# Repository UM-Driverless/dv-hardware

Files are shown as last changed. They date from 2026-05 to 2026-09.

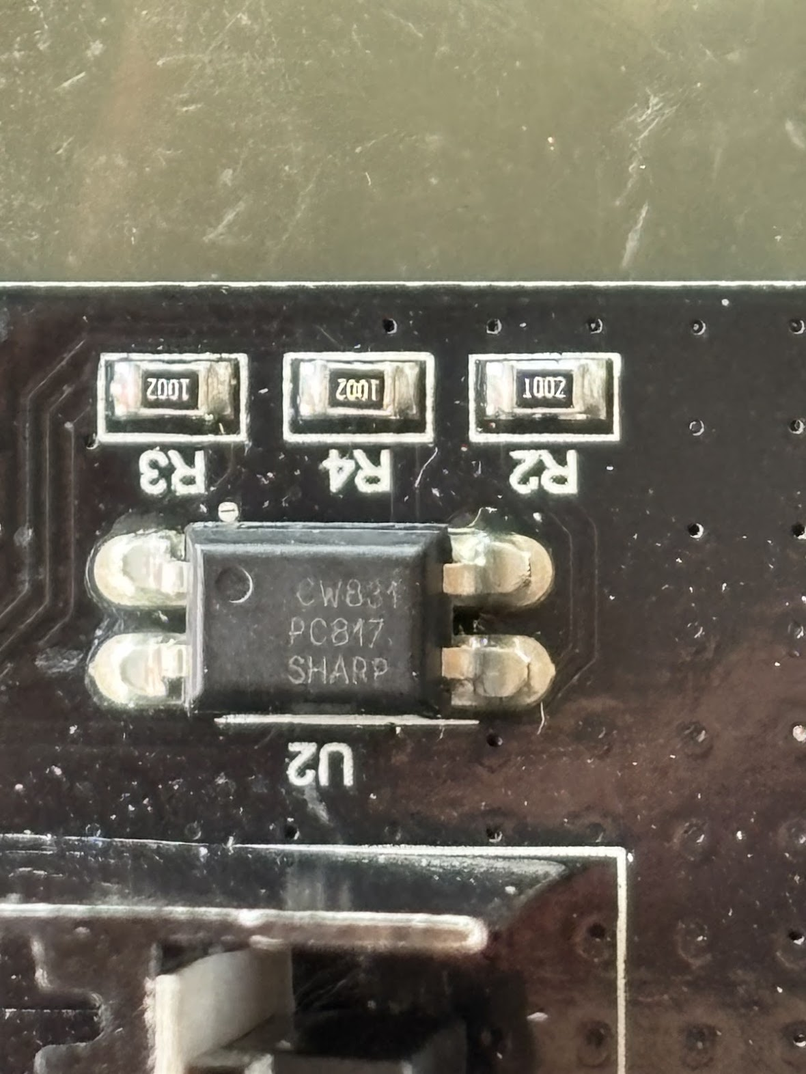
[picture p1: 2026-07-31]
projects/kart-medulla/docs/images/compressor-module-U2-PC817.png

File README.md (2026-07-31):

# dv-hardware

Hardware (KiCad) projects for the Driverless section of U-Motorsport (URJC Formula Student).

Firmware lives in [UM-Driverless/kart-medulla](https://github.com/UM-Driverless/kart-medulla). Pair board revisions with firmware releases via matching git tags (e.g. `medulla-v1.2` here, `medulla-v1.2-fw` there).

## Layout
```
lib/                 shared symbols, footprints, 3D models — referenced by every project
projects/<board>/    one folder per board (KiCad project, EasyEDA source archive,
                     the board's requirements.md, tasks.md and docs/)
tasks.md             cross-board tasks + the index of every per-board task board
fab/<board>/<rev>/   released Gerbers, BOM, pick-and-place, JLC zip
docs/                cross-board notes
.agents/             agent-readable project knowledge (history, errors)
```

## Board identity
A manufactured board is identified by the commit in this repo that its gerbers were exported from,
written on the board as a QR code or label (short hash is enough). Firmware repos quote that hash to
declare which hardware they target. Because rework exists on a physical board and in no commit, each
board also carries a rework list alongside its hash. Worked example and the boards that exist:
[`projects/kart-medulla/README.md`](projects/kart-medulla/README.md).

## Migration status
Projects originate in EasyEDA Pro and are being migrated to KiCad 9. Each `projects/<board>/` keeps:
- `easyeda-source/` — original `.epro` exports for reference (do not edit)
- `<board>.kicad_pro` (and friends) — the live KiCad project after import

## First-time setup

Install **KiCad 10.x** with the **3D shapes** package included (default in the official installer). The boards reference `${KICAD10_3DMODEL_DIR}` for standard parts (caps, resistors, SOIC, SOT, headers, …); without that variable set, the 3D viewer comes up empty.

After installing, verify the path:

- macOS: `KiCad → Settings… → Configure Paths…` → row `KICAD10_3DMODEL_DIR` should point to `/Applications/KiCad/KiCad.app/Contents/SharedSupport/3dmodels`
- Linux: `/usr/share/kicad/3dmodels`
- Windows: `C:\Program Files\KiCad\10.0\share\kicad\3dmodels`

Project-specific 3D models (parts not in KiCad's standard library — connectors, the MAX4660, …) live next to the board under `projects/<board>/3dmodels/` and are referenced via `${KIPRJMOD}/3dmodels/...` so they travel with the repo.

## Workflow
1. `git pull --rebase` before starting work.
2. One person per board at a time — coordinate in chat. KiCad files are text but not line-mergeable.
3. Commit small, commit often.
4. Run `kicad-cli sch erc` and `kicad-cli pcb drc` before fab. CI does this automatically (TODO).

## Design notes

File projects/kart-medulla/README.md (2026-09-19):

# kart-medulla

PCB pairs with the firmware in [UM-Driverless/kart-medulla](https://github.com/UM-Driverless/kart-medulla).

Originally called "ESP32 Expander" in EasyEDA (Jan 2026), renamed to "Kart Medulla (expander for ESP 32)" in May 2026. Both EasyEDA exports kept under `easyeda-source/` for diff history.

## Board identity

**A manufactured board is identified by the dv-hardware commit its gerbers were exported from**,
written on the board as a QR code or label — short form is enough, e.g. `84d6dd0`. Firmware repos
quote that hash to say which hardware they target, so "does this code match this board?" is a
question anyone can answer by reading the board.

Use the **gerber-export** commit, not the last commit that touched the schematic. They are usually
different, and only the export is what a fab house ever received.

**A board stops matching its hash the moment it is reworked.** The hash names the design it was made
from; a lifted pin or a patch wire exists on that one physical board and in no commit. So each board
also carries a rework list below. A rework entry may name the commit whose behaviour it brings the
board up to — that is how a patched board gets described precisely without inventing a new
identifier for it.

### Boards in existence

**`84d6dd0`** — "medulla: add fabrication gerbers + drill files (zip for fab)". The last commit
touching `fabrication/`, so it is the best available evidence of what the fab house received;
inferred from this repo rather than read off a purchase order. Paired with kart-brain `main` at
`c200e56`. Also reachable as the git tag `kart-medulla-v1`, which is only an alias — the hash is
what the board carries and what firmware quotes.

Two pins are also used for something other than their designed signal on this board (the steering
sensor's PWM on `PRESSURE_3`, the compressor MOSFET gate on `BUZZER`) — that is firmware assignment
rather than copper, so it is listed in
[`docs/pinout-kart-medulla-v1.md`](docs/pinout-kart-medulla-v1.md) under "As-built pin use". Read both that section
and the list below to know what this board actually does.

Rework outstanding on this board:

- **CN10.2 brake output is on the wrong side of the LM358.** The board carries the unamplified 0-5 V
  DAC output where the valve needs 0-10 V, and the U13.10 -> U1.3 copper (DAC to amplifier input) is
  unrouted. Fixed in the design by `f68cc1f`, which is *after* this board was made, so the board
  still has the fault. Needs a physical patch — see [`tasks.md`](tasks.md).
- **R10 removed, to read the steering sensor's PWM on GPIO 1.** The `PRESSURE_3` front end is
  `CN5.2 —[R8 10k]— node —[R9 10k]— GPIO 1 —[R10 10k]— GND`. R10 is the only shunt to ground, so
  removing it (and only it) turns the terminal into a usable digital input; R8 + R9 stay as a 20 kΩ
  series, which is far too high-impedance for the ADC — that is why this pin is decoded as PWM with
  the MCPWM capture peripheral rather than read as an analog voltage. Recorded here 2026-07-31; the
  reasoning and the wiring context are on the kart-docs medulla page.
- **Check for abandoned throttle-bypass rework.** The working throttle path uses MCP4922 channel A:
  a 2026-08-08 workshop video records it working with the “new DAC chip at 5 volts,” and the kart
  later accelerated on command under remote control. The record does not establish whether the
  original chip was faulty or exactly when it was changed.
  The temporary GPIO 38 filtered-PWM firmware path was reverted. Inspect this physical board for a
  leftover flying wire from GPIO 38 toward U14 pin 8 and confirm U13 pin 14 was not left lifted; remove
  the wire and restore the pin if either change was ever soldered. See the firmware repo's `tasks.md`.

## Migration status (2026-05-03)
Converted via [ConvertEDA](https://converteda.com) from EasyEDA Pro 2.2.47.7. KiCad 10.0.1's built-in `Import Non-KiCad Project → EasyEDA Pro` silently failed on this `.epro` (produced empty stubs) — likely a format-version lag against EasyEDA Pro 2.2.47.x. ConvertEDA handled it cleanly.

Renamed all internal references from `Kart_Medulla_(expander_for_ESP_32)` to `kart-medulla` (file names, sheet refs, project name, title block) for consistency with the firmware repo.

### Known cleanup needed (raw conversion baseline)
- 347 ERC violations: mostly missing `gen` symbol library (converter creates `gen:` lib_id refs but doesn't ship the library), `power` library mismatches (`12V`, `+5V_REG` not in KiCad's stdlib power), missing `fp-lib-table`.
- 165 DRC violations + 31 unconnected items: expected until footprint library is registered and net ties verified.

Cleanup work tracked separately. The current commit is the as-converted baseline so future cleanup commits show a clean diff.

## Fonts

Silkscreen text on the PCB uses **DejaVu Sans Mono**. There is no monospace font shared by default between macOS and Ubuntu, so contributors must install it locally:

- **Ubuntu:** ships by default — no action needed.
- **macOS:** `brew install --cask font-dejavu` then restart KiCad.

Alternatively, `File → Board Setup → Embedded Files` lets KiCad embed the font into the .kicad_pcb so it travels with the project. See `history.md` 2026-05-09 entry for details.

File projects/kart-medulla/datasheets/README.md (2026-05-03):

# kart-medulla datasheets

Datasheets for chips actually placed on this board. Copied in from the vault (`~/dv/datasheets/`) when a part is designed onto the PCB. Self-contained so a fresh `git clone` of `dv-hardware` gives you everything needed to understand the board.

## What goes here
- One PDF per chip used in the BOM. Filename: `<partnumber>_<vendor>_datasheet.pdf` (matches vault naming).
- Application notes specific to how *this* board uses the part.

## What does NOT go here
- Datasheets for parts only being evaluated (not yet on the PCB) → keep in vault.
- General electronics reference (op-amp theory, etc.) → vault `references/`.
- Datasheets shared across multiple boards: still copy here per-board (small duplication is OK; lookup pain isn't). The vault remains the master catalog.

## Source of truth
Vault `~/dv/datasheets/` is the team's full chip catalog. This folder is the per-board subset.

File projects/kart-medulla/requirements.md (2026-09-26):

<!-- reference — read when scoping a board revision -->

# kart-medulla — requirements

What the board must do. Durable: survives revisions and task pruning.

- **This file** = the target (what the board must do, in every revision).
- **`tasks.md`** (next to this file) = the work for this board (pruned as items are done).
  The cross-board board is the repo root `tasks.md`, which indexes it.
- **`pinout-esp32-s3.md` / `pinout-cn-connectors.md`** = the as-built pin-by-pin reality.

Signals are named here, never pin-mapped — pin assignments live in the pinout docs only.

`[built]` means the assembled board already meets it and the next revision must not lose it.
`[v2]` means the next revision has work to do. Every requirement links to its entry in
[Notes](#notes), which carries the reasoning, the numbers and the traps — read that entry
before drawing the thing. Cite requirements elsewhere by ID, not by quoting the line, so
rewording here does not break the reference.

## Requirements

- **REQ-01 — Push-in terminal connectors, rated for what they carry.** No dupont. WAGO
  2601-31xx, wires exiting outward, pin numbering co-directional with CN numbering on each
  side. `[v2]` [Why](#req-01)
- **REQ-02 — Read 3 motor hall sensors.** 5 V digital, level-translated to 3.3 V. `[built]`
  [Why](#req-02)
- **REQ-03 — Read 3 Festo pressure sensors.** 0–10 V analog. `[v2]` [Why](#req-03)
- **REQ-04 — Write the kart accelerator command.** 5 V analog. `[built]` [Why](#req-04)
- **REQ-05 — Write the Festo brake-valve command, across its full 0–10 V range.** `[v2]`
  [Why](#req-05)
- **REQ-06 — Cut the shutdown circuit on command.** `[built]` [Why](#req-06)
- **REQ-07 — Give the steering sensor its own PWM-capable input.** GPIO 38, no divider and no
  filter capacitor. `[v2]` [Why](#req-07)
- **REQ-08 — Every output that can move the kart reaches its safe state through a component,
  not through code.** Pulldowns on `CMD_STEER_PWM` and `CMD_STEER_DIR`. `[v2]` [Why](#req-08)
- **REQ-09 — Separate power and signal ground.** Distinct net classes for Power GND
  (compressor, heavy actuators) and Signal GND (ESP32, logic). `[v2]` [Why](#req-09)
- **REQ-10 — Bring at least two spare GPIOs out to terminals.** Unassigned, PWM-capable,
  non-strap. `[v2]` [Why](#req-10)
- **REQ-11 — Switch the EBS compressor on the board, motor current included.** The compressor
  MOSFET module stuck onto the assembled board today becomes part of the PCB. `[v2]`
  [Why](#req-11)
- **REQ-12 — Read the final state of the shutdown circuit.** 12 V digital input from the shutdown MOSFET. `[v2]` [Why](#req-12)
- **REQ-13 — Connect the board to a CAN bus.** 3.3 V transceiver on the board, CANH and CANL
  on terminals. `[v2]` [Why](#req-13)

**Explicitly not a requirement:** an ASSI or AS-emergency buzzer. FS-Rules DV 4.5 applies to
the formula vehicle, not this kart — Rubén, 2026-07-18. The `BUZZER` net name on GPIO 3 /
CN8.2 is historical; that pin is the compressor's permanently.

## Notes

### REQ-01 — Push-in terminal connectors, rated for what they carry

From the original brief: carry the ESP32 and make connections easier with wago-like push-in
connectors, not arduino-style dupont.

The fitted Phoenix 1990012 is rated 2 A and v2 carries the compressor's 6 A, so the connector
family changes to the team's WAGO standard (17.5 A, 3.5 mm pitch, top entry). This replaces an
earlier "rotate the push-in connectors" requirement: swapping the part makes rotating the old
one moot, and the two things that requirement wanted become placement rules for the new
footprints — **wires exit outward, away from the board, and pin numbering runs co-directional
with the CN numbering on each side.** Note the pitch change from 2.5 mm widens every connector
and affects the board outline.

### REQ-02 — Read 3 motor hall sensors

5 V digital, level-translated to 3.3 V. From the original brief; met by the assembled board.

### REQ-03 — Read 3 Festo pressure sensors

0–10 V analog, a voltage divider may suffice. **Still three. Confirmed 2026-07-31 by Rubén**,
overriding a 2026-07-18 reading that dropped it to two.

On the assembled board only two work: `PRESSURE_3` (GPIO 1, CN5.2) was repurposed to read the
steering sensor's PWM angle output. On v2 that pin goes back to `PRESSURE_3` and the steering
sensor moves to GPIO 38 — see [REQ-07](#req-07) and the v2 pin allocation in
`docs/pinout-esp32-s3.md`.

An earlier version of this said the opposite, that GPIO 1 was not coming back and the third
pressure channel needed a new pin. That is not possible: ADC1 is GPIO 1–10 and ADC2 is unusable
with WiFi on, so there are exactly ten analog-capable pins, and seven analog inputs plus the
compressor gate on GPIO 3 and I²C on GPIO 8/9 already fills them. Something non-analog has to
leave ADC1, and the steering PWM is the one that costs nothing to move.

### REQ-04 — Write the kart accelerator command

5 V analog. From the original brief; met by the assembled board.

### REQ-05 — Write the Festo brake-valve command, across its full 0–10 V range

The brake command chain is the MCP4922 DAC (0–3.3 V, since U13 moved to +3V3 on 2026-08-01) →
an LM358 ×3 non-inverting stage (U1, R19 2 kΩ / R20 1 kΩ) → the Festo VPPM proportional valve.
U1 is supplied from +12 V and the LM358 is not rail-to-rail: TI SLOS068AB §5.7 gives 3 V max
swing from the positive rail, so a worst-case part reaches only 9 V where the valve wants 10 V,
and the kart's unregulated 12 V sagging under load pushes that lower.

Accepted on the assembled board (the VPPM is ~1 bar per volt, so it costs the top ~1 bar of a
range the kart does not use) but the next revision should deliver the full range — either supply
U1 from 24 V, or fit a rail-to-rail-output op-amp in the same SOIC-8 footprint. Until it is
fixed, firmware must not treat DAC full scale as 10 bar: the achievable maximum varies between
boards, so any target above ~9 bar needs closed-loop control against a pressure sensor. Full
working and the trade-off between the two fixes: "Give the pressure-command amplifier full
0–10 V swing on the next board revision" in [`tasks.md`](tasks.md).

### REQ-06 — Cut the shutdown circuit on command

The original brief asked for a normally-open relay able to cut the shutdown circuit on
condition. The assembled board does it with a MOSFET instead of a relay (Q3, IRLZ44N, gate
pulled low by R23 so the chain sits open until firmware drives it) — the requirement is the
function, not the part.

### REQ-07 — Give the steering sensor its own PWM-capable input

Decided 2026-07-18. On the assembled board the steering sensor's PWM angle output is read on
GPIO 1, the pin silkscreened `PRES3` on CN5.2. That works, but every name still says "pressure
sensor 3", so the schematic, the netlist, the silkscreen and the firmware all describe something
the board does not do. For v2:

- **Rename the net and the silkscreen** to what it is — e.g. `STEER_SENS_PWM` — across the
  schematic, `pinout-esp32-s3.md`, `pinout-cn-connectors.md` and the firmware pin map.
- **Drop the ADC divider** on that input. It was drawn for an 0–10 V analog sensor; the steering
  sensor is a 3.3 V logic PWM output and does not want a divider in front of it.
- **Choose the pin deliberately** rather than inheriting it from a pressure channel. The sensor
  itself is not settled — AS5600, MT6701 and MA732 are all under evaluation (datasheets in the
  `kart-medulla` repo), and MT6701/MA732 offer SSI/SPI as well as PWM, so the pin choice should
  not foreclose that.
- **`STEER_SENS_PWM` moves to GPIO 38**, amended 2026-07-31 after the ADC1 count in
  [REQ-03](#req-03). GPIO 38 is unconstrained, is not a strap pin and is on neither ADC, so a PWM
  capture input wastes nothing there. `PRESSURE_3` returns to GPIO 1 with the divider it already
  has.
- **GPIO 38 must get no divider and no filter capacitor.** A 1/3 divider puts a 3.3 V logic high
  at 1.100 V against the ESP32's 2.475 V VIH, and 100 nF against that source impedance gives a
  239 Hz corner on a 994.4 Hz PWM frame. Both are correct for an analog pressure input and fatal
  for a logic-level one.

### REQ-08 — Every output that can move the kart reaches its safe state through a component

Raised 2026-08-08, after the steering swung to full lock and broke teeth off the steering gears
while the ESP32-S3 was being reflashed. The kart was in autonomous at the time and the motor was
live: the Cytron H-bridge is fed permanently from the 48 V traction pack, deliberately, so it is
powered whenever the kart is.

The board treats its actuators inconsistently, and steering is on the wrong side of the split:

- **Throttle is safe.** It passes through the MAX4660 mux (U14), whose `SELECT_THROTTLE` line
  carries a 10 kΩ pulldown (R32) to GND. An ESP32 that is unbooted, resetting, crashed or removed
  leaves the mux in manual passthrough — the driver's pedal — by physics.
- **The compressor is safe.** Its MOSFET gate has a 100 kΩ pulldown holding it off through boot.
- **Steering is not.** `CMD_STEER_PWM` and `CMD_STEER_DIR` run from the ESP32 to the Cytron with
  nothing in between and no pull resistors, so whenever the ESP32 is not actively driving them
  the motor's behaviour is whatever the floating lines happen to look like to the Cytron's
  inputs. The only thing that has ever held steering off is firmware writing zero — which does
  not exist during a reset, and a reset is part of every flash.

So: a pulldown to GND on `CMD_STEER_PWM` and on `CMD_STEER_DIR`, sized like R32 rather than
relying on the ESP32's internal pulls — the internal ones are ~45 kΩ and, more importantly, only
exist once firmware has configured them, which is exactly the window that broke the gears. Place
them at the Cytron end of each net so an unplugged connector is also covered.

Check when drawing it: the firmware drives the Cytron in sign-magnitude mode, PWM duty for
magnitude and a separate DIR pin for sign, so a low PWM line means the motor is off. **Verify the
Cytron's mode-select switches actually select that mode.** Under a locked-antiphase scheme a low
PWM line means full reverse, and the pulldown would cause the failure it is meant to prevent.

Ask the same question of every other output on the board before fab, not just this one: for each,
what does the kart do while the ESP32 is held in reset? Any answer other than "nothing" needs a
resistor.

Firmware has been changed alongside this (kart-medulla `2092130`) to drive both steering pins low
as the first action of `KM_GPIO_Init` and enable their internal pulldowns. That shortens the
undriven window to the earliest instant code can act, and does not close it — the bootloader
window remains, and only the external resistors cover it.

### REQ-09 — Separate power and signal ground

Distinct net classes for Power GND (compressor, heavy actuators) and Signal GND (ESP32, logic).

### REQ-10 — Bring at least two spare GPIOs out to terminals

Unassigned, PWM-capable, non-strap, on every revision. From 2026-07-10: *a spare pin you cannot
reach with a screwdriver is not a spare pin.* Concretely, route GPIO 38 → CN3.1 and GPIO 39 →
CN3.2; the first is the intended `CMD_COMPRESSOR_PWM`.

### REQ-11 — Switch the EBS compressor on the board, motor current included

Reconfirmed 2026-07-31: integrate it, the less wiring the better. V2 carries the MOSFET, its gate
drive, the flyback diode and the bulk capacitance, copying the already-validated module circuit
(bridge rectifier removed, 330 Ω optocoupler LED resistor for 3.3 V drive).

**Where that module is today.** On the assembled board the compressor MOSFET module is not part of
the PCB: it is a separate module stuck onto the board (Gabriel, 2026-09-26).
That is the part v2 removes. Its circuit moves into the board's own copper, so the next board is
built without a module stuck to it.

This is a power-section change before it is a component addition. The assembled board takes `+12V`
in at CN1 pin 2 and feeds only the on-board regulator for the logic/analog rail, roughly **1 mA,
7 mW**, with copper sized for that. The answer is to change the copper, not to keep the compressor
off the board: *the less wiring, the better*, and the kart currently runs two boxes that v2 is
meant to collapse into one.

**What makes it tractable is that the circuit already exists and is validated.** The compressor
MOSFET module in service has had its **bridge rectifier removed** and the **series resistor
feeding the optocoupler's LED changed to 330 Ω**, which makes its input work when driven from
3.3 V. It works, and more of the same modules are in stock. V2 copies that circuit onto the PCB
rather than designing a fresh gate-drive stage. The module has to be identified and its schematic
traced first — see the compressor task in [`tasks.md`](tasks.md).

**What v2 must get right:**

- **Track and via sizing.** `+12V` and the motor return are drawn today for a ~1 mA supply. They
  must be re-drawn (or poured) for a stated design current, with the via count to match, and that
  current written down. No component addition fixes copper sized for a different job — Rubén's
  emphasis: this is the important part.
- **A connector rated for the load**, which is what [REQ-01](#req-01) is for. The compressor
  measured **6 A running at 60 % duty** (bench, 2026-07-18). The Phoenix 1990012 terminals fitted
  as CN1–CN10 are rated **2 A** and cannot carry it. The **WAGO 2601-3103** already on the buy list
  is rated **17.5 A** and can. Deutsch **DT** (13 A per size-16 contact) is the team's harness
  standard if a sealed connector is wanted; **DTM** at 7.5 A is tight. Soldering the wire straight
  to the board is an accepted fallback. Ratings and sources:
  [`../../docs/connectors.md`](../../docs/connectors.md).
- **Nothing is gained by measuring locked-rotor inrush.** Decided 2026-07-31: the circuit is
  validated in service and over-sizing costs nothing when the parts are already in stock. Size
  generously from what is on the shelf instead of measuring the peak and designing to it.

### REQ-12 — Read the final state of the shutdown circuit

Read the final state of the shutdown circuit (the wire that goes to the MOSFET). The 12 V signal needs a voltage divider or optocoupler to step it down to a 3.3 V logic input so the ESP32 can read the emergency state.

### REQ-13 — Connect the board to a CAN bus

Decided 2026-09-26 by Gabriel, answering the question Rubén raised on 2026-07-31: is there room
for CAN on the board? The assembled board has no CAN interface; on the kart today, CAN lives on
the Orin carrier board. V2 carries one.

- **The pins cost nothing.** The pinout docs already hold two ESP32 pins for `CAN_RX` and
  `CAN_TX`. Neither is ADC-capable and neither is a strap pin, so no other signal loses its pin,
  and the GPIO expander is not involved.
- **A 3.3 V transceiver on the board**, SN65HVD230 or TCAN332 class. New part, new footprint.
  `CAN_TX` and `CAN_RX` only run from the ESP32 to the transceiver, so they never need terminals.
- **Two terminal pins for CANH and CANL.** This is the real cost: terminal positions are scarce.
  Allocate them as part of the single v2 pin and terminal allocation (see "Decide the medulla-v2
  pinout as one allocation" in [`tasks.md`](tasks.md)), not on their own.
- **Termination.** 120 Ω between CANH and CANL if the medulla is one end of the bus, nothing if it
  sits on a stub. Which one depends on where the bus runs on the kart.

**Not settled yet:** what the medulla will send or receive over CAN. The team keeps its CAN
message definitions (DBC files) in `~/dv/can/`. This requirement is the interface; the traffic is
decided with the firmware.

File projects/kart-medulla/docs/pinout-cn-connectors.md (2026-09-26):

# Push-in connector pinout (CN1–CN10)

> **Authoritative source: the schematic in this same project folder (`../kart-medulla.kicad_sch` + `../kart-medulla_P1.kicad_sch`).** This document mirrors the per-CN pin assignments for human reading. When this doc and the schematic disagree, the schematic wins; fix this file. Re-verify before each fab release.

The medulla PCB has 10 three-pin push-in (1990012) connectors arranged around the ESP32-S3 dev module. Each CN is a 3-pin Wago-style cage-clamp terminal; wires terminate independently per pin (no per-CN cable grouping is required — see `history.md` 2026-05-08 for context).

Connectors are placed in a "chip-pinout" layout to minimize jumper-wire length to the ESP32 module:

  - CN1–CN5 sit on the **right** side of the PCB, **bottom→top** (CN1 closest to USB, CN5 closest to the top edge). They map onto ESP32 pins 1–22 (right edge, RIGHT_HEADER).
  - CN6–CN10 sit on the **left** side, **top→bottom** (CN6 closest to the top edge, CN10 closest to USB). They map onto ESP32 pins 23–44 (left edge, LEFT_HEADER).

Pin numbering within each CN (verified against `kart-medulla.kicad_pcb`, 2026-07-10 — this
used to read "pin 1/2/3 from top to bottom", which is only true of the right-hand side):

  - **CN1–CN5** (right, footprint rotation −90°): pin **1 at top**, pin 3 at bottom.
  - **CN6–CN10** (left, footprint rotation +90°): pin **1 at bottom**, pin 3 at top.

Note the consequence: on the right the CNs advance bottom→top while their pins advance
top→bottom; on the left the CNs advance top→bottom while their pins advance bottom→top. So on
**both** sides the pin numbering runs *counter* to the CN numbering, and on both sides the wire
entry faces **inward**, toward the middle of the board. See the "flip the connectors" task in
`../tasks.md`.

Footprint is `CONN-TH_3P-P2.50-S5.00_1990012`: 2.50 mm pitch, and the pads are **staggered** —
pins 1 and 3 in one row, pin 2 in a row 5.00 mm across. A 180° rotation therefore moves pin 2's
pad row to the opposite side and is not a free change; the copper under each connector must be
re-routed.

## Silkscreen is the authority (v1, the only board that exists)

The table below is transcribed from the **v1 PCB silkscreen** — v1 is the only revision built, so
this is what is physically in front of you:

```
CN1        CN2        CN3        CN4       CN5        CN6        CN7        CN8         CN9          CN10
1 +3V3     1 HALL3    1 EXP_P1   1 SCL     1 HYD2     1 PED_BRK  1 PRES1    1 SDC       1 STEER_PWM  1 CMD_ACC
2 +12V     2 HALL2    2 EXP_P2   2 SDA     2 PRES3    2 PED_ACC  2 PRES2    2 BUZZ      2 HYD1       2 CMD_BRK
3 GND      3 +5V      3 EXP_P3   3 REV     3 EXP_P4   3 +3V3     3 HALL1    3 STEER_DIR 3 GND        3 GND
```

**Two naming traps, both of which have already caused confusion:**

1. **`BUZZ` on CN8.2 is an OLD name.** There is no buzzer on it. The net was repurposed to
   `CMD_COMPRESSOR_PWM` — GPIO 3 driving the EBS compressor MOSFET gate. Wherever `BUZZER` appears
   in this repo it should be read as *(old name)*. Note this collides with the rules-mandated ASSI
   buzzer, which still needs a home — see `projects/kart-medulla/tasks.md`.
2. **`EXP_P2` is CN3.2, and always has been.** A stale export of `projects/kart-medulla/output/netlist.net`
   (dated 7 May, re-exported 2026-08-10 and now current with the schematic) used to list
   `CN8.2 → /EXP_P2` and show Q3's and Q4's gates on no net at all — both artifacts of the schematic
   having moved on without a re-export. Re-exporting fixed both; the netlist now agrees with the
   silkscreen and this table. If a future edit makes them disagree again, trust the silkscreen and
   this table until the netlist is re-exported.
3. **Designator mismatch: schematic vs the fabricated v1 board.** An earlier draft of the schematic
   (before the netlist above was current) put the pressure channels on `CN2.1`/`CN2.2`/`CN2.3`. On
   the v1 silkscreen and PCB — the only board that physically exists — those pins are
   `CN7.1`/`CN7.2`/`CN5.2`, and PCB `CN2` is instead `HALL3`/`HALL2`/`+5V_REG` (see the assignment
   table below). **Anyone wiring the kart should read from the silkscreen/PCB, never from a
   schematic printout**, in case a future schematic edit drifts from the fabricated board again
   before a new revision is built.

## Assignment table

Each row is one independent terminal. `CN5.2` means connector CN5, pin 2.
The three pins in a connector do **not** imply a shared device or cable.
“Board label” is the text printed on the built board; the function describes its current use.

| Terminal | Board label | Signal and function |
|---|---|---|
| **CN1.1** | `+3V3` | `+3V3` — 3.3 V supply output from the ESP32 module. |
| **CN1.2** | `+12V` | `+12V` — 12 V supply input from the kart battery. |
| **CN1.3** | `GND` | `GND` — Ground return. |
| **CN2.1** | `HALL3` | `MOTOR_HALL_3` — Motor Hall sensor 3 input, 5 V. |
| **CN2.2** | `HALL2` | `MOTOR_HALL_2` — Motor Hall sensor 2 input, 5 V. |
| **CN2.3** | `+5V` | `+5V_REG` — 5 V rail for the motor Hall sensors. |
| **CN3.1** | `EXP_P1` | `EXP_P1` — PCF8574 expander pin P1. |
| **CN3.2** | `EXP_P2` | `EXP_P2` — PCF8574 expander pin P2. |
| **CN3.3** | `EXP_P3` | `EXP_P3` — PCF8574 expander pin P3. |
| **CN4.1** | `SCL` | `SCL` — I²C (Inter-Integrated Circuit) clock, 3.3 V. |
| **CN4.2** | `SDA` | `SDA` — I²C data, 3.3 V. |
| **CN4.3** | `REV` | `REVERSE_WIRE` — Reverse command from PCF8574 P0; open-drain output shared with the manual reverse button. |
| **CN5.1** | `HYD2` | `HYDRAULIC_2` — Hydraulic pressure sensor 2 input, 0–5 V. |
| **CN5.2** | `PRES3` | `CMD_STEER_PWM_IN` — MT6701 steering-angle input, pulse-width modulation (PWM). Repurposed pressure input; no pressure sensor here. |
| **CN5.3** | `EXP_P4` | `EXP_P4` — Spare PCF8574 expander pin P4. |
| **CN6.1** | `PED_BRK` | `PEDAL_BRAKE` — Brake pedal position input, 0–5 V. |
| **CN6.2** | `PED_ACC` | `PEDAL_ACC` — Accelerator pedal position input, 0–5 V. |
| **CN6.3** | `+3V3` | `+3V3` — 3.3 V supply output from the ESP32 module. |
| **CN7.1** | `PRES1` | `PRESSURE_1` — Pneumatic pressure sensor 1 input, 0–10 V through a divider. |
| **CN7.2** | `PRES2` | `PRESSURE_2` — Pneumatic pressure sensor 2 input, 0–10 V through a divider. |
| **CN7.3** | `HALL1` | `MOTOR_HALL_1` — Motor Hall sensor 1 input, 5 V. |
| **CN8.1** | `SDC` | `SDC_IN_LOW_SIDE` — Shutdown circuit (SDC) return, connected to Q3 drain. See voltage reference below. |
| **CN8.2** | `BUZZ` | `CMD_COMPRESSOR_PWM` — 3.3 V command to the external compressor transistor gate; not a buzzer or compressor power supply. |
| **CN8.3** | `STEER_DIR` | `CMD_STEER_DIR` — Cytron steering H-bridge direction output, 3.3 V. |
| **CN9.1** | `STEER_PWM` | `CMD_STEER_PWM` — Cytron steering H-bridge PWM output, 3.3 V. |
| **CN9.2** | `HYD1` | `HYDRAULIC_1` — Hydraulic pressure sensor 1 input, 0–5 V. |
| **CN9.3** | `GND` | `GND` — Ground return. |
| **CN10.1** | `CMD_ACC` | `CMD_ACC` — Throttle command to the motor controller, nominal 0–5 V. |
| **CN10.2** | `CMD_BRK` | `CMD_PRES` — Pressure setpoint for the Festo VPPM regulator, nominal 0–10 V. See output circuit notes below. |
| **CN10.3** | `GND` | `GND` — Ground return and reference for the VPPM setpoint; common with the 24 V supply’s 0 V. |

### Bus and sensor connections

CN4.1 and CN4.2 expose the bus shared with the on-board PCF8574 (U25). The
AS5600 connection used these bus lines; the MT6701 steering-angle PWM input is
CN5.2. CN4.3 is an independent reverse command.

CN5.2 is silkscreened `PRES3`, but its current use is steering-angle capture on
ESP32 GPIO 1. See “As-built pin use — board `84d6dd0`” in `pinout-esp32-s3.md`.
CN8.2 is silkscreened `BUZZ`, but GPIO 3 drives the gate resistor of the external
compressor MOSFET (metal-oxide-semiconductor field-effect transistor).

### Output circuit notes (CN10)

Pin 1 = throttle command, to the motor controller: MCP4922 VOUTA (0–3.3 V) goes through the LM358 U1B non-inverting stage (gain 1.51, set by R37 5.1K / R38 10K, giving 4.99 V full scale) straight to CN10.1. Nothing is muxed on this path — the MAX4660 (U14) that used to sit here has been deleted from the schematic; the panel DPDT switch on the kart, downstream of this board, is what selects whether the motor controller listens to this command or to the driver's pedal.

Pin 2 = **pressure command to the Festo VPPM proportional regulator, not to the motor controller** — braking on this kart is pneumatic. It is VOUTB amplified ×3 by the LM358 (U1A) (R19 = 2K, R20 = 1K), so 9.9 V leaves the board, not 10 V exactly, since the DAC's full scale is 3.3 V rather than 5 V — the MCP4922 U13 was moved from +5V to +3V3 on 2026-08-01 (commit 16a35fb) to fix an SPI logic-threshold problem. The net was called `CMD_BRAKE` until 2026-07-31; it is `CMD_PRES__0_10V` now, because the signal is a pressure setpoint for a proportional regulator rather than a brake-force command. The silkscreen on the built board still reads `CMD_BRK`.

Pin 3 = GND, and it is also the **return the VPPM's setpoint is measured against**: the valve runs from a separate 24 V supply, so that supply's 0 V must be common with the medulla's GND or the commanded pressure shifts by whatever the offset is.

## The pneumatic side — three devices, three supplies, only one of them on a medulla pin

Written 2026-07-31 because "the valve" was being used to mean different things. Sources:
`~/dv/kart/pneumatics/README.md` and `~/dv/kart/pneumatics/history.md` (2026-05-30).

| Device | Festo part | Its own supply | What the medulla does |
|---|---|---|---|
| **VPPM-8L proportional pressure regulator** | 571293 | **24 V DC** (21.6–26.4 V, 300 mA, 7 W) from a UENPO 9–36 V → 24 V buck-boost | Drives its **0–10 V setpoint** out of **CN10.2** (`CMD_PRES__0_10V`). GND on **CN10.3** is the return that setpoint is measured against. The medulla does **not** supply its 24 V. |
| **EBS emergency electrovalve** (and the ASB valve) | 8035174 / 8035167, VUVS-LT25 | **12 V** coils, switched by the **shutdown relay** | Nothing. No medulla pin touches it. |
| **SDE5 pressure sensors** | 567465 | 15–30 V, fed from the same 24 V rail | Reads their **0–10 V outputs** on `PRESSURE_1`/`PRESSURE_2` (CN7.1, CN7.2) through dividers |

The setpoint and the supply are different things on the VPPM: 0–10 V is the command, 24 V is what
powers the valve. When a note here says a 24 V fault could reach a medulla pin, it means the VPPM's
supply appearing on CN10.2 through a harness fault — not the EBS valve, which is 12 V and not wired
to this board at all.

The VPPM setpoint is a signal input and the LM358 drives it directly; its input impedance was
treated as an open question until 2026-07-31 and is not one.
## Voltage levels — quick reference

| Suffix in signal name | Meaning |
|---|---|
| `__3V3` | 3.3 V logic level (ESP32 native) |
| `__5V` | 5 V logic level (motor hall, level-shifted by U5 to 3V3 before reaching the ESP32) |
| `__0_5V` | analog 0–5 V (sensors, DAC outputs) |
| `__0_10V` | analog 0–10 V (pressure sensors) |
| no suffix on power names (`+12V`, `+3V3`, `+5V_REG`) | rail of that nominal voltage |

`SDC_IN_LOW_SIDE` is the drain of Q3 (IRLZ44N): nominally 0 V when Q3 conducts (no emergency), floats up to whatever the upstream SDC node sits at (≤ 12 V) when Q3 is off (emergency). Treat it as a 12-V-tolerant line.

## Power architecture summary (where each rail comes from)

  - `+12V`         — externally, from the kart battery, via **CN1 pin 2**.
  - `+5V_REG`      — on-board L7805CDT linear regulator (U19), or the external XW-1224 5 V rail tied in via the same net, feeds the `+5V_REG` global net.
  - `+3V3`         — generated by the ESP32-S3 module's on-board LDO from its 5 V input. Available on LEFT_HEADER pins 23/24 of the dev module.
  - `+5V_USB`      — independent 5 V rail from the medulla USB-C connector; powers only the ESP32 dev module (split-rail design, see `pinout-esp32-s3.md`).

The single `power:+12V` symbol that asserts the `+12V` rail name is placed at CN1 pin 2 (the entry point). Same convention applies to `+3V3` and `+5V_REG` symbols on whichever CN exports them — the symbol just declares the rail and can sit anywhere on the net.

## Cross-reference

  - ESP32 module pinout → `pinout-esp32-s3.md` (which GPIO drives which signal in the table above).
  - PCB physical layout / silkscreen → the `kart-medulla.kicad_pcb` file in this folder. The silkscreen legend that lists the 21 numbered external signals is being updated to match this assignment.
  - Decision history → `../../../history.md` entry `2026-05-08 — kart-medulla CN1–CN10 pin assignments locked to ESP32 geometry`.

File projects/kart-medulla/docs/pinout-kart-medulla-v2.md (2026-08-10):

# ESP32-S3 (WROOM-1-N16R8) — kart-medulla v2 (in progress)

> **Authoritative source: the schematic in this same project folder (`../kart-medulla.kicad_sch`).** This document mirrors the pin assignments for human reading and adds rationale/strap-pin/firmware-mode notes that the schematic doesn't carry. **PCB layout is in progress — pin assignments may shift as routing constraints surface.** When this doc and the schematic disagree, the schematic wins; fix this file. Re-verify before each fab release.
>
> **Looking for the physical kart's current wiring?** Scroll down to the **"As-built pin use — board 84d6dd0"** section. The main table below documents the v2 design currently being drawn.

Status legend (refreshed 2026-05-08):
  BLOCKED       — physically off-limits. Hardware constraint, never reclaim.
                  Examples: dev-board USB-UART bridge owns GPIO 43/44; dev-board
                  on-board RGB LED on GPIO 48; USB_D+/- pins not wired on this
                  PCB.
  HOLD          — pin works, currently unassigned, kept free for future
                  expansion. Includes octal-PSRAM-shared pins on N8R8 (GPIO
                  33-37 — usable on N8R2 but held free for module-variant
                  compatibility), conditional-strap pins (usable post-boot if
                  signal's idle-state matches the strap default), and pins
                  parked for known-but-not-yet-wired functions like CAN.
                  Don't grab without team agreement.
  NC            — pin physically not wired on this PCB rev. ERC silenced via
                  no-connect symbol.
  (signal)      — assigned, in use.

Older labels in git history: RESERVED ≈ today's BLOCKED, SPARE ≈ today's HOLD.

Each row's Notes column gives a brief reason for SPARE / RESERVED / SPARE/<sig>.

Column meanings:
  Pin        — physical-position index for the module, treated like an IC:
               bottom-right pin is **1**, count counter-clockwise around the
               ESP32-S3 dev board (component side, USB-C at the top).
                 Pins 1–22  = right edge, bottom (Pin 1) to top (Pin 22).
                 Pins 23–44 = left edge, top (Pin 23) to bottom (Pin 44).
               This is the canonical way to refer to a contact in
               conversation, on a multimeter probe, or in assembly notes.
               **Always use Pin (1–44).** Never use the schematic-symbol pin
               numbers from EasyEDA's connector parts — those are different
               (see "Schematic-symbol pin mapping" below for translation).
  Silkscreen — what's printed on the dev board next to that pin. Espressif
               labels GPIOs by their bare GPIO number (e.g. `4`, `15`, `46`)
               and adds short labels for special pins (`GND`, `3V3`, `5V`,
               `EN`, `TX`, `RX`). Useful when probing or hand-soldering.
  GPIO       — Espressif GPIO number (the one you use in firmware). Some
               pins are pure power/reset and have no GPIO.
  Signal     — net name on the schematic (see "Net Name Nomenclature" in README.md).
  Type       — peripheral / electrical role (ADC1_CHx, SPI, UART, Power, etc.).

Three references for the same physical contact:
  - "Where is it on the dev board physically?" → Pin
  - "What's printed on the board next to it?"  → Silkscreen
  - "What do I write in code?"                 → GPIO

## Schematic-symbol pin mapping

The medulla schematic uses two connector symbols:

- **RIGHT_HEADER** (on the right of the schematic, single row, 22 pins):
  the symbol's pin numbers map 1:1 to our Pin numbering. Symbol pin N = Pin N
  (for N = 1..22).
- **LEFT_HEADER** (on the left of the schematic, dual-row stacked, 44 contact
  pads but only 22 unique nets — each row is shorted between its two physical
  pads for daughterboard pass-through): symbol pins (1, 2) carry one signal,
  (3, 4) the next, etc. Each row maps to one Pin: row k → Pin (22 + k).
  - Symbol pin 1 (and 2) → Pin 23
  - Symbol pin 3 (and 4) → Pin 24
  - …
  - Symbol pin 43 (and 44) → Pin 44

(The PCB-header numbering H1.x / H2.x existed in earlier revisions of this
doc but was removed on 2026-05-02 — see `history.md`.)

Note on octal PSRAM pins (GPIO 33-37): a quad-PSRAM module (N8R2) leaves
these pins available externally. An octal-PSRAM module (N8R8 / N16R8) wires
them to the in-package PSRAM die, so they are internally reserved. The board
is laid out so it accepts either module — GPIO 35-37 are kept as SPARE on the
headers, no signal is routed to them. See history.md (2026-04-29) for rationale.

**The module actually fitted is an N16R8 (octal PSRAM)** — the supplier shipped
it instead of the ordered N8R2; verified on hardware 2026-07-10 (see
`history.md`). So on this board GPIO 33-37 are *not* reclaimable in practice:
treat them as BLOCKED, not HOLD, unless the module is swapped for a quad-PSRAM
part. The variant-agnostic layout means no signal has to move.

## Dev-board compatibility checklist (when buying a non-Espressif S3 board)

The pinout above targets the bare ESP32-S3-WROOM-1 module. Generic dev
boards (AliExpress clones, etc.) usually carry the same module on a
breakout PCB, but a few details vary between vendors and must be checked
before assuming this pinout works:

1. **Module variant.** Confirm whether the board carries an N8R2 (quad
   PSRAM, GPIO 33-37 free) or an N*R8 like N8R8 / N16R8 (octal PSRAM, GPIO
   33-37 reserved internally). The pinout is laid out to be safe with
   either — GPIO 35-37 are SPARE, GPIO 33-34 are unused, and signals that
   used to live on octal-PSRAM pins were moved (BUZZER (old name) 36→3, MOTOR_HALL_1
   37→16, CMD_STEER_DIR 35→0). So **either variant works**, but if you
   end up with an octal-PSRAM module **do not assign anything to GPIO
   33-37 in firmware**, ever.

2. **Native USB-OTG routing.** The pinout uses GPIO 19/20 as USB D-/D+ to
   the Orin. On the official Espressif DevKitC-1, two USB-C ports are
   provided: one wired to GPIO 19/20 (native USB), one to a UART bridge
   on GPIO 43/44. Generic clones vary — some wire their single USB-C only
   to a UART bridge (no native USB at all), some wire it to GPIO 19/20
   directly, some have both ports like the official board. **Verify with
   a multimeter on arrival**: continuity from the dev-board USB-C D+ pad
   to GPIO 20 and D- pad to GPIO 19. If GPIO 19/20 are not reachable
   through the on-board USB connector, the board still works for the
   medulla *only* if those GPIOs are exposed on the pin headers (so the
   medulla PCB can route them to its own USB-C connector toward the
   Orin). If 19/20 aren't broken out at all, the board is unsuitable.

3. **Physical footprint.** The medulla PCB headers (H1.1-22, H2.1-22)
   assume the Espressif **ESP32-S3-DevKitC-1** outline:
   - Board outline:           **25.40 mm × ~62.7 mm** (1000 mil × 2470 mil)
   - Pin pitch within a row:  **2.54 mm** (0.1 ″ / 100 mil)
   - Pins per row:            **22** (44 total)
   - Row-to-row centerline:   **22.86 mm** (0.9 ″ / 900 mil) —
                              pin holes sit **1.27 mm inside each PCB edge**,
                              so centerline spacing = PCB width − 2 × 1.27.
                              This is the standard Espressif DevKitC
                              footprint, kept consistent between the classic
                              ESP32-DevKitC and the S3-DevKitC-1.
   - USB-C connectors protrude ~8.00 mm past the bottom edge.

   **Confirmed by physical measurement on a teammate's official Espressif
   ESP32-S3-DevKitC-1 (2026-05-02):** caliper-imprecise centerline-to-
   centerline ≈ 24 mm, and the photo clearly shows pin centerlines inset
   from the PCB outline. 22.86 mm matches; 25.40 mm does not.

   Source documents (mirrored locally in `resources/esp32-s3-devkitc-1/`):
   - Espressif official mechanical drawing
     (`DXF_ESP32-S3-DevKitC-1_V1.1_20220429.pdf`) — board outline 25.40 mm
     and pin pitch 2.54 mm. The two `1.27 mm` callouts at the top of the
     drawing are most likely the edge-to-pin-row-centerline offsets,
     giving the 22.86 mm row spacing. The drawing is ambiguous enough
     that this was misread twice in 2026-05-01 → see `history.md` for
     the incident; trust the physical measurement and the 0.9 ″ DevKitC
     convention over any single PDF callout.
   - Espressif official schematic
     (`SCH_ESP32-S3-DevKitC-1_V1.1_20221130.pdf`) — for USB / RGB / button
     wiring; not for mechanical dimensions.

   ⚠ **Do NOT trust the UIOPAL clone vendor drawing in `resources/`** for
   this measurement. It shows `1000 mil` and `1100 mil` callouts that
   were misinterpreted as PCB-vs-outer-envelope on 2026-05-01. The
   physical measurement on the official board contradicts that reading.
   The clone may have a different layout, or the labels were misread.

   Clones (AliExpress, etc.) mostly match the official 22.86 mm footprint
   but not always — row count, board length, and row spacing have all
   been seen to differ on no-name boards. Before committing to
   manufacturing the medulla PCB, place the actual dev board on a printed
   1:1 paper copy of the footprint and confirm every pin lands on its
   pad. Photos in listings are not reliable for this.

| Pin | Silkscreen | GPIO | Signal | Type | Notes |
|---|---|---|---|---|---|
| 1 | GND | - | GND | Power | Ground (bottom of right edge / RIGHT_HEADER pin 1) |
| 2 | GND | - | GND | Power | Ground |
| 3 | 19 | 19 | NC | - | No USB-C connector on the medulla PCB. GPIO 19 is brought to the header but unwired in this rev (Orin USB link goes elsewhere). Marked NC in schematic. |
| 4 | 20 | 20 | NC | - | Same as Pin 3 — no USB connector on this board, GPIO 20 unwired. |
| 5 | 21 | 21 | MOTOR_HALL_3 | Digital In | Motor hall sensor 3 |
| 6 | 47 | 47 | MOTOR_HALL_2 | Digital In | Motor hall sensor 2 |
| 7 | 48 | 48 | BLOCKED | - | Dev-module's on-board RGB LED. No external LED on the medulla PCB. NC in schematic, BLOCKED label. |
| 8 | 45 | 45 | HOLD | - | Strap pin (VDD_SPI voltage select, flash/boot risk). Reclaimable post-boot if signal's idle state matches the strap default (LOW for 3.3V flash). |
| 9 | 0 | 0 | HOLD | - | BOOT-mode strap pin (must be HIGH at boot for normal boot). Was previously assigned to `CMD_STEER_DIR` (signal moved to GPIO 17 on 2026-05-08 to remove the strap-pin risk from real signals). Reclaimable for any signal that is HIGH or high-Z at power-on. |
| 10 | 35 | 35 | HOLD | - | Octal-PSRAM pin. Internally reserved on the fitted N16R8 — unusable in practice. Kept as HOLD (not BLOCKED) because the layout also accepts a quad-PSRAM N8R2, where it would be free. |
| 11 | 36 | 36 | HOLD | - | Octal-PSRAM pin on N8R8 — same as Pin 10. (Was briefly assigned to CMD_REVERSE on 2026-05-02; moved to PCF8574 P0 on 2026-05-03 to restore N8R8 compatibility.) |
| 12 | 37 | 37 | HOLD | - | Octal-PSRAM pin on N8R8 — same as Pin 10. |
| 13 | 38 | 38 | STEER_SENS_PWM | PWM capture (MCPWM) | MT6701 steering-angle sensor PWM output. Moved here from GPIO 1 for v2. Unconstrained, no strap, not ADC. |
| 14 | 39 | 39 | HOLD | - | Unconstrained GPIO. Earlier doc revisions described `SDC_ENABLE` here — that signal never existed in the schematic; the ESP32's contribution to the SDC chain is the GPIO driving Q3 directly (see Pin 33 / GPIO 18). |
| 15 | 40 | 40 | CMD_STEER_PWM | LEDC PWM | Steering motor PWM (Cytron H-bridge). |
| 16 | 41 | 41 | HOLD | - | Held for future CAN_RX (CAN currently moved to Orin carrier; medulla has no transceiver in this rev). |
| 17 | 42 | 42 | HOLD | - | Held for future CAN_TX (same as Pin 16). |
| 18 | 2 | 2 | HYDRAULIC_2 | ADC1_CH1 | Hydraulic pressure sensor 2 (input only) |
| 19 | 1 | 1 | PRESSURE_3 | ADC1_CH0 | Pressure sensor 3 (input only). Restored to its original analog function for v2 (steering sensor moved to GPIO 38). |
| 20 | RX | 44 | BLOCKED | - | Owned by the dev-module's USB-UART bridge (UART0 RX0). Not reclaimable — the bridge IC drives this pin from the USB-C port of the DevKitC-1. |
| 21 | TX | 43 | BLOCKED | - | Same as Pin 20 — UART0 TX0, owned by the dev-module USB-UART bridge. |
| 22 | GND | - | GND | Power | Ground (top of right edge / RIGHT_HEADER pin 22) |
| 23 | 3V3 | - | 3V3 | Power | 3.3V supply (generated by S3 module LDO from 5V input) — top of left edge / LEFT_HEADER row 1 |
| 24 | 3V3 | - | 3V3 | Power | 3.3V supply |
| 25 | EN | - | RST | Reset | Reset (Espressif silkscreens this as `EN` for chip enable) |
| 26 | 4 | 4 | PEDAL_ACC | ADC1_CH3 | Accelerator pedal (input only) |
| 27 | 5 | 5 | PEDAL_BRAKE | ADC1_CH4 | Brake pedal |
| 28 | 6 | 6 | PRESSURE_1 | ADC1_CH5 | Pressure sensor 1 (input only) |
| 29 | 7 | 7 | PRESSURE_2 | ADC1_CH6 | Pressure sensor 2 (input only) |
| 30 | 15 | 15 | SDC_STATUS | Digital In | Reads the final state of the shutdown circuit (`SDC_IN_LOW_SIDE`). The 12 V signal from the drain of Q3 passes through a 10 kΩ / 3.3 kΩ voltage divider to safely reach 3.3 V logic levels here. Assigned 2026-08-11. |
| 31 | 16 | 16 | MOTOR_HALL_1 | Digital In | Motor hall sensor 1 (moved from GPIO 37 for N8R8 compatibility) |
| 32 | 17 | 17 | CMD_STEER_DIR__3V3 | Digital Out | Steering motor direction (Cytron H-bridge). Moved here from GPIO 0 on 2026-05-08 to remove the BOOT-strap risk; now sits on the left side of the ESP32 alongside SDC_NOT_EMERGENCY. (UART1 TX default — but UART pins are remappable on ESP32-S3.) |
| 33 | 18 | 18 | SDC_NOT_EMERGENCY__3V3 | Digital Out | Drives the gate of Q3 (IRLZ44N) through R22 (100 Ω). When HIGH, Q3 conducts and pulls `SDC_IN_LOW_SIDE` to GND, completing the kart's SDC chain return path → no emergency. When LOW, Q3 is off and the SDC chain is broken → emergency. R23 (100 kΩ) gate-pulldown ensures Q3 is OFF (= emergency) at boot until firmware drives it HIGH. The signal name reads as the *intent* the ESP32 is asserting, not the chain's electrical state. Moved here from GPIO 38 on 2026-05-08 so the gate driver sits on the left side of the PCB next to the MOSFET. (UART1 RX default — remappable.) |
| 34 | 8 | 8 | SDA | I2C | I²C data — AS5600 steering angle sensor + PCF8574 I/O expander share this bus |
| 35 | 3 | 3 | CMD_COMPRESSOR_PWM | Digital Out | EBS Compressor MOSFET gate. GPIO 3 floats at reset with no internal pull, so an external pulldown wins at boot, making it safe to drive a gate. (Historically `BUZZER`, but kart carries no buzzer). |
| 36 | 46 | 46 | HOLD | - | Strap pin (ROM-print enable, flash/boot risk). Default LOW = no boot-message print, which is what we want. Reclaimable post-boot if signal's idle state is LOW at power-on. |
| 37 | 9 | 9 | SCL | I2C | I²C clock — same bus as SDA |
| 38 | 10 | 10 | HYDRAULIC_1 | ADC1_CH9 | Hydraulic pressure sensor 1 (input only) |
| 39 | 11 | 11 | MOSI | SPI | SPI data out (→ MCP4922 SDI). Also referred to as `OUT_SDI` in some parts of the schematic. |
| 40 | 12 | 12 | CLK | SPI | SPI clock (→ MCP4922 SCK). Also `OUT_SCK` in some schematic labels. |
| 41 | 13 | 13 | MISO | SPI | SPI data in. Unused by MCP4922 (write-only DAC); available for future SPI peripheral. |
| 42 | 14 | 14 | CMD_DAC_CS | SPI | MCP4922 chip select (active low). Also `OUT_CS` in some schematic labels. |
| 43 | 5V | - | +5V_USB | Power | 5V from USB VBUS via the medulla USB-C connector — powers the ESP32 dev board only (split-rail design, see history.md 2026-05-02). NOT connected to the L7805 +5V_REG rail. |
| 44 | GND | - | GND | Power | Ground (bottom of left edge / LEFT_HEADER row 22) |

## medulla-v2 pin allocation — decided 2026-07-31, as one table

Decided together rather than signal by signal, which is what let `PRESSURE_3` and `BUZZER` get
quietly repurposed on v1. Inputs to it: MT6701 stays on PWM, the MCP4922 stays as the throttle DAC,
and the op-amp keeps its 12 V rail (all Rubén, 2026-07-31).

**The constraint that drives the whole table: ADC1 is full.** On the ESP32-S3, ADC1 is GPIO 1–10 and
ADC2 is GPIO 11–20 — and ADC2 is unusable whenever WiFi is on, so in practice this board has exactly
**ten analog-capable pins**. v2 needs **seven** of them (`PEDAL_ACC`, `PEDAL_BRAKE`, `PRESSURE_1`,
`PRESSURE_2`, `PRESSURE_3`, `HYDRAULIC_1`, `HYDRAULIC_2`). All ten are currently occupied, four by
signals that are not analog at all: the steering-sensor PWM on GPIO 1, the compressor gate on GPIO 3,
and I²C on GPIO 8 and 9. Six analog + four squatters = ten, so restoring the third pressure channel
means evicting one squatter.

**Evict the steering sensor, not I²C.** Moving `STEER_SENS_PWM` from GPIO 1 to **GPIO 38** costs
nothing: GPIO 38 is an unconstrained HOLD today, is not a strap pin, is not on either ADC, and a PWM
capture input does not care which pin it sits on. That returns GPIO 1 to `PRESSURE_3`, its originally
designed use, and it is what `requirements.md` already asks for — the steering sensor gets a pin
chosen for it rather than inherited from a pressure channel. Moving I²C instead would work but
touches two pins and the firmware bus setup for no extra gain.

*(The full table that was here has been merged into the main document table above, which now serves as the authoritative v2 pinout).*

**No pin carries two signals, every strap pin is left alone, and the two ADC-capable pins spent on
non-analog signals (3 and 8/9) are spent deliberately.**

Two things this table does *not* solve, because they are connector capacity rather than GPIO
capacity: `SDC_ENABLE` still has no terminal to leave through, and CN4 gives the steering encoder its
two bus lines but neither power nor ground. See the connector audit in `tasks.md`.

**Firmware impact:** one pin number changes, `STEER_SENS_PWM` from GPIO 1 to GPIO 38. Everything else
keeps its current assignment.

## As-built pin use — board `84d6dd0`

**The table above is the *design*. This section is the *board that exists*, and it lists only the pins
whose real use differs.** Everything not listed here is used as the table says. Exceptions-only is
deliberate: a second full table would drift out of sync with the first one within a revision.

Physical modifications (cut traces, patch wires) are **not** here — they live in the per-board rework
list in [`../README.md`](../README.md), keyed to the same hash. This section is firmware-side pin
assignment; that one is copper. A person holding the board needs both.

| Pin | GPIO | Designed signal | Actual use on `84d6dd0` | Status |
|---|---|---|---|---|
| 19 | 1 | `PRESSURE_3` (ADC1_CH0) | **Reads the MT6701 steering-angle sensor's PWM output.** | Decided 2026-07-31 (Rubén). Pressure sensor 3 is not fitted on this board. |
| 35 | 3 | `BUZZER` (Digital Out) | **Drives the compressor MOSFET gate.** | Reassigned 2026-07-10 (see `../../../history.md`); and **permanent** — the kart carries no buzzer or ASSI at all (closed 2026-07-18; those are formula-vehicle only), so the `BUZZER` net name is historical. GPIO 3 floats at reset with no internal pull, so an external pulldown wins at boot — which is what makes it safe on a gate. |
| 13 | 38 | `HOLD` (unassigned) | **Planned:** raw ESP32 PWM → RC low-pass → U14 pin 8, as the throttle command, bypassing the SPI/MCP4922 path. | **Not done, and now obsolete.** It targeted the MAX4660 mux U14, which is fitted on this fabricated board but was deleted from the schematic on 2026-08-08 (a CMOS switch passes nothing unpowered, and the kart's panel DPDT switch already selects the throttle source downstream). The throttle command now leaves the board through the LM358 U1B gain stage instead. The 66 % shortfall this was meant to work around no longer exists: U1B now scales the DAC's 0–3.3 V up to 4.99 V before it leaves the board. |

Neither the pressure-3 sensor nor the buzzer is populated on this board, so both reassignments are
free — no signal was displaced. Record any further deviation here the day it is decided, not the day
the firmware is written; the point of this section is that someone probing the board can trust it.

## MCP4922 (dual 12-bit SPI DAC) — external chip connections on the PCB

| Pin | Signal | Connects to |
|---|---|---|
| VDD | +3V3 | 3.3 V rail. Moved from 5 V on 2026-08-01 (commit `16a35fb`): the MCP4922 datasheet DS22250A p7 sets VIH min = 0.7 × VDD, so a 5 V supply demanded 3.5 V on the SPI pins, which a 3.3 V ESP32 cannot reach. |
| VSS | GND | Ground |
| SHDN | +3V3 | Tied high (DAC always enabled) |
| LDAC | GND | Tied low → every SPI write latches to output immediately |
| CS | → ESP32 GPIO14 (CMD_DAC_CS) | |
| SCK | → ESP32 GPIO12 (CLK) | |
| SDI | → ESP32 GPIO11 (MOSI) | |
| VREFA | +3V3 via RC filter | 100 Ω series + 10 µF ceramic to GND, placed next to chip. Full scale on VOUTA is therefore 3.3 V. |
| VREFB | +3V3 via RC filter | 100 Ω series + 10 µF ceramic to GND (can share filter node). Full scale on VOUTB is therefore 3.3 V. |
| VOUTA | `CMD_ACC_ESP32__0_3V3` | Accelerator analog command, **0–3.3 V** at the DAC pin (U13 pin 14). It is amplified before leaving the board: U13 pin 14 → U1 pin 5 (LM358 U1B, +IN2), a non-inverting stage of gain 1.51 set by R37 5.1 kΩ and R38 10 kΩ, so full scale is **4.99 V** on U1 pin 7, which is the net `CMD_ACC__0_5V` and goes straight to CN10.1. This closes the earlier shortfall where a 3.3 V command reached only ~66 % of the motor controller's 0–5 V input range. |
| VOUTB | `CMD_PRES_DAC__0_3V3` | Pressure command, **0–3.3 V at the DAC pin**. It does not leave the board at that level: U1A (LM358) amplifies it ×3 (R19 2 kΩ / R20 1 kΩ) and CN10.2 exports **0–9.9 V** to the Festo VPPM proportional regulator. |

RC filter purpose: attenuates ~150 kHz switching ripple from the XW-1224 buck
by ~60 dB at the DAC reference pins. DAC VREF draws <100 µA so the 100 Ω
series resistor drops <10 mV (negligible vs 5V).

## Power architecture

```
Kart 12V battery ─┬─→ XW-1224 buck (external, 5A) ──→ 5V kart-wide rail
                  │                                   │
                  │                                   ├→ Medulla PCB 5V (H1.21)
                  │                                   │   │
                  │                                   │   ├→ ESP32-S3 module VIN ─→ module LDO ─→ 3.3V
                  │                                   │   └→ other on-board 3.3 V loads, including
                  │                                   │      MCP4922 VDD and its VREFA/VREFB filter
                  │                                   │
                  │                                   └→ other kart 5V loads
                  │
                  ├─→ L7805CDT linear regulator (U19, DPAK) ──→ the on-board +5V_REG rail.
                  │   THIS IS WHAT IS FITTED. Since the MAX4660 throttle mux U14 was deleted
                  │   from the schematic on 2026-08-08, this rail reaches only CN2 pin 3, plus
                  │   its own decoupling C3 (0.1 µF) and C4 (4.7 µF) — U14 was its only other
                  │   consumer. The MCP4922 (U13) moved to +3V3 on 2026-08-01 (commit 16a35fb).
                  │   The load is about 1 mA, 7 mW of heat, so a linear part is fine here. An
                  │   LM2596SX-ADJ buck (qty 8 in stock) was the alternative and was NOT taken;
                  │   settled 2026-07-31 against the schematic, where U19 = L7805CDT.
                  │
                  └─→ Cytron H-bridge 12V (steering driver) — permanently powered, NOT gated by
                      the manual/autonomous mode switch. Decision 2026-05-01: routing the Cytron
                      through the mode switch caused inrush brownouts on the Orin every time the
                      kart was switched to autonomous. See history.md (2026-05-01) for details.
                      The PCB only routes signals (CMD_STEER_PWM, CMD_STEER_DIR) to the Cytron,
                      not power. Firmware also commands PWM = 0 in manual — but that is a courtesy,
                      not the safety measure: the mode switch's second pole physically breaks the
                      cable from the Cytron to the steering motor in manual, so the motor is
                      disconnected regardless of what firmware does. Clarified 2026-08-08; the
                      earlier wording implied firmware was the only thing holding steering off.
```

## Manual/autonomous signal selection (throttle mux deleted 2026-08-08; I²C-driven reverse, decision 2026-05-01 / refined 2026-05-02 / brake-mux dropped 2026-05-08 / reverse moved to PCF8574 2026-05-03)

> **The MAX4660 throttle mux (U14) has been deleted from the schematic, on 2026-08-08.** Deleted with
> it: R32, the 10 kΩ pulldown on `SELECT_THROTTLE`, and C5, U14's local 100 nF decoupling capacitor.
> The part is still fitted on the fabricated v1 board. Two reasons for the removal:
>
> 1. **It is redundant.** The kart's panel DPDT mode switch already selects the throttle source
>    downstream of this board — the pedal or the medulla's `CMD_ACC__0_5V` on CN10.1 — so U14 was a
>    second selector in series doing the same job.
> 2. **It does not do what it was believed to do.** The design assumed U14 passed the pedal through
>    when the medulla was unpowered. It does not: it is a CMOS switch, so at V+ = 0 V both channel
>    MOSFETs are off and only ESD diodes remain, so the pedal is disconnected and instead backfeeds
>    the dead `+5V_REG` rail. "Normally closed" in the datasheet means closed at logic 0 **with power
>    applied**. The panel switch, with real metal contacts, is what actually provides the unpowered
>    manual path.
>
> The removal also resolves the open blocker that U14 ran from `+5V_REG` against a +9 V datasheet
> minimum, and it frees GPIO 15. The medulla now always outputs its autonomous throttle command and
> the panel switch decides whether anything listens. Full evidence in `history.md`, 2026-08-08.

The throttle analog signal is no longer muxed on this board: the path is MCP4922 U13 pin 14 (VOUTA,
0–3.3 V) → U1 pin 5 (LM358 U1B, +IN2), a non-inverting stage of gain 1.51 set by R37 5.1 kΩ and R38
10 kΩ giving 4.99 V full scale → U1 pin 7, the net `CMD_ACC__0_5V`, straight to CN10.1
(net `CMD_ACC__0_5V`). Brake is **not** muxed either — manual mode does not need brake control routed
through the ESP32, so the brake signal goes straight from the MCP4922 to the motor
electronics with no switch. The digital reverse signal does not use an analog switch
either — it is driven by **U25 PCF8574T port P0** (I²C GPIO expander, pin 4)
wired in parallel with the manual reverse button (wired-OR via the motor
controller's existing pull-up). The PCF8574's quasi-bidirectional outputs are
natively open-drain with a weak internal pull-up, so the wired-OR is electrically
correct without any extra components. Steering is NOT muxed (ESP32 drives the
Cytron directly; PWM = 0 in manual mode).

See `~/dv/kart/kart-medulla/history.md` for the full design history — entries
`2026-05-01` (initial PCB-mux design), `2026-05-02` (reverse refinement to
open-drain on a direct ESP32 GPIO), `2026-05-03` (reverse moved off the ESP32
onto PCF8574 P0 to free GPIO 36 and gain N8R8 compatibility), `2026-05-08`
(brake mux dropped).

| Chip / signal | Type | Manual source | Autonomous source | Output |
|---|---|---|---|---|
| **LM358 U1B, ×1.51 non-inverting (throttle)** | analog 0–3.3 V in, 0–4.99 V out | (n/a — the pedal reaches the motor electronics through the kart's panel DPDT switch, not through this board) | MCP4922 VOUTA (U13 pin 14) = `CMD_ACC_ESP32__0_3V3` | U1 pin 5 → U1 pin 7 (**R37 5.1 kΩ / R38 10 kΩ, gain 1.51**) → CN10.1 (`CMD_ACC__0_5V`). **No mux on the PCB** since U14 was deleted on 2026-08-08; the panel switch chooses between this output and the pedal. |
| **LM358 U1A, ×3 non-inverting (pressure)** | analog 0–3.3 V in, 0–9.9 V out | (n/a — manual brake bypasses ESP32) | MCP4922 VOUTB = `CMD_PRES_DAC__0_3V3` | LM358 U1A (**R19 2 kΩ / R20 1 kΩ, gain 3** as of 2026-08-01, because U13 now runs from +3V3) → `CMD_PRES__0_10V` → CN10.2 → Festo VPPM. **No mux on the PCB** — the DAC always owns the command and the only way to release it is to write zero. |
| **U25 PCF8574T pin 4 / P0** | digital | Manual reverse button (in parallel) | I²C-controlled `CMD_REVERSE` (open-drain via PCF8574) | → kart-electronics-box REVERSE wire |

No ESP32 GPIO selects the throttle source any more. GPIO 15 drove the deleted
MAX4660's SELECT pin through the net `SELECT_THROTTLE`, and is now free.

`CMD_REVERSE` is asserted by writing to PCF8574 port P0 over I²C (same bus as
`SDA__I2C` / `SCL__I2C` on ESP32 GPIO 8 / 9, shared with the AS5600 steering
sensor). The PCF8574 P0 output is in parallel with the manual reverse button.
The motor controller's REVERSE input already has its own pull-up to 5 V (that
is why the button works by pulling the line LOW). Both the button and P0 can
only sink to GND, never push HIGH actively → wired-OR with no electrical
conflict. Fail-safe property: ESP32 or I²C bus dead → P0 stays high-Z (or in
its power-on default state, all outputs high) → only the button controls the
line (identical to the current manual-only setup).

**Firmware note**: `CMD_REVERSE` is set/cleared by writing the PCF8574 output
register over I²C. The PCF8574 is quasi-bidirectional, so writing `1` releases
the line (high-Z + weak pull-up), writing `0` pulls it LOW. No special "open-drain"
mode flag needed — the chip is built that way. There is no longer a direct ESP32
GPIO-mode constraint for CMD_REVERSE.

### GPIO assignments (current schematic)

Module variant in use: **WROOM-1-N16R8** (16 MB flash, 8 MB octal PSRAM) —
verified on hardware 2026-07-10. The ESP32 GPIOs involved in manual/autonomous source selection:

| Signal | GPIO | Notes |
|---|---|---|
| `SDC_STATUS` | 15 | Reads the 12 V final state of the shutdown circuit via a 10 kΩ series / 3.3 kΩ shunt voltage divider. |
| `SDA__I2C` / `SCL__I2C` | 8 / 9 | I²C bus shared by AS5600 (steering angle) and PCF8574 (GPIO expander, drives `CMD_REVERSE` and EXP_P1..P7). |

`CMD_REVERSE` no longer consumes an ESP32 GPIO directly. With the PCF8574
indirection the design is fully N8R8-compatible — no signal depends on the
quad-PSRAM-only GPIOs (33-37).

Other signals related to this design:
- `PEDAL_ACC__0_5V` (entering at CN6.2 — CN6.1 is `PEDAL_BRAKE__0_5V`) is read by the ESP32 via ADC and nothing else on this board. It used to branch inside the schematic to the NC pin of the MAX4660 mux U14 as the manual throttle source, but U14 was deleted on 2026-08-08 and the pedal now reaches the motor electronics only through the kart's panel DPDT switch, outside this board. There is no separate `MANUAL_THR` / `PEDAL_THR` signal. Same pattern for `MANUAL_BRK`: the brake mux was dropped 2026-05-08, so manual brake never enters the medulla; the manual brake source goes directly to the brake valve driver on the kart side.
- `CMD_STEER_PWM` (GPIO 40) and `CMD_STEER_DIR` (GPIO 0) — unchanged, feed the Cytron directly with no switch in between.
- `U12` (PC357N1J000F opto with planned BSS123 swap) for driving the kart REVERSE wire is now redundant — the ESP32 GPIO open-drain output drives the line directly. **TODO**: decide whether to remove U12 from the schematic or keep it as an inline buffer. Default plan: remove for simplicity.

### Datasheet references

Datasheets live in the shared `dv/datasheets/` folder (one canonical copy per part, indexed in `dv/datasheets/README.md`). Per-board project folders hold integration-specific docs only (e.g. `kart/kart-medulla/resources/esp32-s3-devkitc-1/` keeps mechanical drawings + the local clone-vendor PDF, not the chip datasheet itself).

- **MAX4660EUA+T** (U14, the throttle mux — deleted from the schematic 2026-08-08, still fitted on the fabricated v1 board): `dv/datasheets/max4660_analogdevices_datasheet.pdf` (mirrored 2026-05-02; canonical URL <https://www.analog.com/media/en/technical-documentation/data-sheets/MAX4659-MAX4660.pdf>).
- **L7805CDT** (U19, the fitted 12 V → 5 V regulator): <https://item.szlcsc.com/datasheet/L7805CDT/21968527.html>.
- **LM2596SX-ADJ** (evaluated, not fitted): `dv/datasheets/lm2596_ti_datasheet.pdf` (mirrored 2026-05-02).

---

# Legacy: classic ESP32 (previous board, kept for reference)

| Pin | Header | GPIO | Signal | Type | Notes |
|---|---|---|---|---|---|
| 1 | H1.1 | 6 | RESERVED | - | FLASH/SDIO |
| 2 | H1.2 | 7 | RESERVED | - | FLASH/SDIO |
| 3 | H1.3 | 8 | RESERVED | - | FLASH/SDIO |
| 4 | H1.4 | 15 | RESERVED | - | STRAP pin (boot config risk) |
| 5 | H1.5 | 2 | STATUS_LED | Digital Out | Onboard LED (strap pin, keep LOW at boot) |
| 6 | H1.6 | 0 | RESERVED | - | STRAP pin (BOOT mode) |
| 7 | H1.7 | 4 | RESERVED | - | STRAP pin (boot config risk) |
| 8 | H1.8 | 16 | MOTOR_HALL_3 | Digital In | Motor hall sensor 3 (also UART2 RX) |
| 9 | H1.9 | 17 | MOTOR_HALL_1 | Digital In | Motor hall sensor 1 (also UART2 TX) |
| 10 | H1.10 | 5 | RESERVED | - | STRAP pin (boot config risk) |
| 11 | H1.11 | 18 | CMD_STEER_PWM | LEDC PWM | Steering motor PWM (Cytron H-bridge) |
| 12 | H1.12 | 19 | CMD_STEER_DIR | Digital Out | Steering motor direction (Cytron H-bridge) |
| 13 | H1.13 | - | GND | Power | Ground |
| 14 | H1.14 | 21 | I2C_SDA | I2C | AS5600 steering angle sensor data |
| 15 | H1.15 | 3 | USB_UART_RX | UART0 RX | Reserved (binary protocol from Orin) |
| 16 | H1.16 | 1 | USB_UART_TX | UART0 TX | Reserved (binary protocol to Orin) |
| 17 | H1.17 | 22 | I2C_SCL | I2C | AS5600 steering angle sensor clock |
| 18 | H1.18 | 23 | SPARE | - | Available |
| 19 | H1.19 | - | GND | Power | Ground |
| 20 | H2.1 | - | 3V3 | Power | 3.3V supply |
| 21 | H2.2 | - | EN | Reset | Active-low reset |
| 22 | H2.3 | 36 (VP) | PRESSURE_1 | ADC1_CH0 | Pressure sensor 1 (input only) |
| 23 | H2.4 | 39 (VN) | PRESSURE_2 | ADC1_CH3 | Pressure sensor 2 (input only) |
| 24 | H2.5 | 34 | PRESSURE_3 | ADC1_CH6 | Pressure sensor 3 (input only) |
| 25 | H2.6 | 35 | PEDAL_ACC | ADC1_CH7 | Accelerator pedal (input only) |
| 26 | H2.7 | 32 | PEDAL_BRAKE | ADC1_CH4 | Brake pedal |
| 27 | H2.8 | 33 | MOTOR_HALL_2 | Digital In | Motor hall sensor 2 |
| 28 | H2.9 | 25 | CMD_ACC | DAC1 | Throttle analog output (0-255) |
| 29 | H2.10 | 26 | CMD_BRAKE | DAC2 | Brake analog output (0-255) |
| 30 | H2.11 | 27 | HYDRAULIC_1 | ADC2_CH7 | Hydraulic pressure sensor 1 |
| 31 | H2.12 | 14 | HYDRAULIC_2 | ADC2_CH6 | Hydraulic pressure sensor 2 |
| 32 | H2.13 | 12 | RESERVED | - | STRAP pin (flash/boot risk) |
| 33 | H2.14 | - | GND | Power | Ground |
| 34 | H2.15 | 13 | SDC_NOT_EMERGENCY | Digital In | Shutdown circuit emergency status |
| 35 | H2.16 | 9 | RESERVED | - | FLASH/SDIO |
| 36 | H2.17 | 10 | RESERVED | - | FLASH/SDIO |
| 37 | H2.18 | 11 | RESERVED | - | FLASH/SDIO |
| 38 | H2.19 | - | 5V | Power | 5V supply |

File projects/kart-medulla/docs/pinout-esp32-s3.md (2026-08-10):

# ESP32-S3 (WROOM-1-N16R8) — current PCB

> **Authoritative source: the schematic in this same project folder (`../kart-medulla.kicad_sch`).** This document mirrors the pin assignments for human reading and adds rationale/strap-pin/firmware-mode notes that the schematic doesn't carry. **PCB layout is in progress — pin assignments may shift as routing constraints surface.** When this doc and the schematic disagree, the schematic wins; fix this file. Re-verify before each fab release.

Status legend (refreshed 2026-05-08):
  BLOCKED       — physically off-limits. Hardware constraint, never reclaim.
                  Examples: dev-board USB-UART bridge owns GPIO 43/44; dev-board
                  on-board RGB LED on GPIO 48; USB_D+/- pins not wired on this
                  PCB.
  HOLD          — pin works, currently unassigned, kept free for future
                  expansion. Includes octal-PSRAM-shared pins on N8R8 (GPIO
                  33-37 — usable on N8R2 but held free for module-variant
                  compatibility), conditional-strap pins (usable post-boot if
                  signal's idle-state matches the strap default), and pins
                  parked for known-but-not-yet-wired functions like CAN.
                  Don't grab without team agreement.
  NC            — pin physically not wired on this PCB rev. ERC silenced via
                  no-connect symbol.
  (signal)      — assigned, in use.

Older labels in git history: RESERVED ≈ today's BLOCKED, SPARE ≈ today's HOLD.

Each row's Notes column gives a brief reason for SPARE / RESERVED / SPARE/<sig>.

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

Three references for the same physical contact:
  - "Where is it on the dev board physically?" → Pin
  - "What's printed on the board next to it?"  → Silkscreen
  - "What do I write in code?"                 → GPIO

## Schematic-symbol pin mapping

The medulla schematic uses two connector symbols:

- **RIGHT_HEADER** (on the right of the schematic, single row, 22 pins):
  the symbol's pin numbers map 1:1 to our Pin numbering. Symbol pin N = Pin N
  (for N = 1..22).
- **LEFT_HEADER** (on the left of the schematic, dual-row stacked, 44 contact
  pads but only 22 unique nets — each row is shorted between its two physical
  pads for daughterboard pass-through): symbol pins (1, 2) carry one signal,
  (3, 4) the next, etc. Each row maps to one Pin: row k → Pin (22 + k).
  - Symbol pin 1 (and 2) → Pin 23
  - Symbol pin 3 (and 4) → Pin 24
  - …
  - Symbol pin 43 (and 44) → Pin 44

(The PCB-header numbering H1.x / H2.x existed in earlier revisions of this
doc but was removed on 2026-05-02 — see `history.md`.)

Note on octal PSRAM pins (GPIO 33-37): a quad-PSRAM module (N8R2) leaves
these pins available externally. An octal-PSRAM module (N8R8 / N16R8) wires
them to the in-package PSRAM die, so they are internally reserved. The board
is laid out so it accepts either module — GPIO 35-37 are kept as SPARE on the
headers, no signal is routed to them. See history.md (2026-04-29) for rationale.

**The module actually fitted is an N16R8 (octal PSRAM)** — the supplier shipped
it instead of the ordered N8R2; verified on hardware 2026-07-10 (see
`history.md`). So on this board GPIO 33-37 are *not* reclaimable in practice:
treat them as BLOCKED, not HOLD, unless the module is swapped for a quad-PSRAM
part. The variant-agnostic layout means no signal has to move.

## Dev-board compatibility checklist (when buying a non-Espressif S3 board)

The pinout above targets the bare ESP32-S3-WROOM-1 module. Generic dev
boards (AliExpress clones, etc.) usually carry the same module on a
breakout PCB, but a few details vary between vendors and must be checked
before assuming this pinout works:

1. **Module variant.** Confirm whether the board carries an N8R2 (quad
   PSRAM, GPIO 33-37 free) or an N*R8 like N8R8 / N16R8 (octal PSRAM, GPIO
   33-37 reserved internally). The pinout is laid out to be safe with
   either — GPIO 35-37 are SPARE, GPIO 33-34 are unused, and signals that
   used to live on octal-PSRAM pins were moved (BUZZER (old name) 36→3, MOTOR_HALL_1
   37→16, CMD_STEER_DIR 35→0). So **either variant works**, but if you
   end up with an octal-PSRAM module **do not assign anything to GPIO
   33-37 in firmware**, ever.

2. **Native USB-OTG routing.** The pinout uses GPIO 19/20 as USB D-/D+ to
   the Orin. On the official Espressif DevKitC-1, two USB-C ports are
   provided: one wired to GPIO 19/20 (native USB), one to a UART bridge
   on GPIO 43/44. Generic clones vary — some wire their single USB-C only
   to a UART bridge (no native USB at all), some wire it to GPIO 19/20
   directly, some have both ports like the official board. **Verify with
   a multimeter on arrival**: continuity from the dev-board USB-C D+ pad
   to GPIO 20 and D- pad to GPIO 19. If GPIO 19/20 are not reachable
   through the on-board USB connector, the board still works for the
   medulla *only* if those GPIOs are exposed on the pin headers (so the
   medulla PCB can route them to its own USB-C connector toward the
   Orin). If 19/20 aren't broken out at all, the board is unsuitable.

3. **Physical footprint.** The medulla PCB headers (H1.1-22, H2.1-22)
   assume the Espressif **ESP32-S3-DevKitC-1** outline:
   - Board outline:           **25.40 mm × ~62.7 mm** (1000 mil × 2470 mil)
   - Pin pitch within a row:  **2.54 mm** (0.1 ″ / 100 mil)
   - Pins per row:            **22** (44 total)
   - Row-to-row centerline:   **22.86 mm** (0.9 ″ / 900 mil) —
                              pin holes sit **1.27 mm inside each PCB edge**,
                              so centerline spacing = PCB width − 2 × 1.27.
                              This is the standard Espressif DevKitC
                              footprint, kept consistent between the classic
                              ESP32-DevKitC and the S3-DevKitC-1.
   - USB-C connectors protrude ~8.00 mm past the bottom edge.

   **Confirmed by physical measurement on a teammate's official Espressif
   ESP32-S3-DevKitC-1 (2026-05-02):** caliper-imprecise centerline-to-
   centerline ≈ 24 mm, and the photo clearly shows pin centerlines inset
   from the PCB outline. 22.86 mm matches; 25.40 mm does not.

   Source documents (mirrored locally in `resources/esp32-s3-devkitc-1/`):
   - Espressif official mechanical drawing
     (`DXF_ESP32-S3-DevKitC-1_V1.1_20220429.pdf`) — board outline 25.40 mm
     and pin pitch 2.54 mm. The two `1.27 mm` callouts at the top of the
     drawing are most likely the edge-to-pin-row-centerline offsets,
     giving the 22.86 mm row spacing. The drawing is ambiguous enough
     that this was misread twice in 2026-05-01 → see `history.md` for
     the incident; trust the physical measurement and the 0.9 ″ DevKitC
     convention over any single PDF callout.
   - Espressif official schematic
     (`SCH_ESP32-S3-DevKitC-1_V1.1_20221130.pdf`) — for USB / RGB / button
     wiring; not for mechanical dimensions.

   ⚠ **Do NOT trust the UIOPAL clone vendor drawing in `resources/`** for
   this measurement. It shows `1000 mil` and `1100 mil` callouts that
   were misinterpreted as PCB-vs-outer-envelope on 2026-05-01. The
   physical measurement on the official board contradicts that reading.
   The clone may have a different layout, or the labels were misread.

   Clones (AliExpress, etc.) mostly match the official 22.86 mm footprint
   but not always — row count, board length, and row spacing have all
   been seen to differ on no-name boards. Before committing to
   manufacturing the medulla PCB, place the actual dev board on a printed
   1:1 paper copy of the footprint and confirm every pin lands on its
   pad. Photos in listings are not reliable for this.

| Pin | Silkscreen | GPIO | Signal | Type | Notes |
|---|---|---|---|---|---|
| 1 | GND | - | GND | Power | Ground (bottom of right edge / RIGHT_HEADER pin 1) |
| 2 | GND | - | GND | Power | Ground |
| 3 | 19 | 19 | NC | - | No USB-C connector on the medulla PCB. GPIO 19 is brought to the header but unwired in this rev (Orin USB link goes elsewhere). Marked NC in schematic. |
| 4 | 20 | 20 | NC | - | Same as Pin 3 — no USB connector on this board, GPIO 20 unwired. |
| 5 | 21 | 21 | MOTOR_HALL_3 | Digital In | Motor hall sensor 3 |
| 6 | 47 | 47 | MOTOR_HALL_2 | Digital In | Motor hall sensor 2 |
| 7 | 48 | 48 | BLOCKED | - | Dev-module's on-board RGB LED. No external LED on the medulla PCB. NC in schematic, BLOCKED label. |
| 8 | 45 | 45 | HOLD | - | Strap pin (VDD_SPI voltage select, flash/boot risk). Reclaimable post-boot if signal's idle state matches the strap default (LOW for 3.3V flash). |
| 9 | 0 | 0 | HOLD | - | BOOT-mode strap pin (must be HIGH at boot for normal boot). Was previously assigned to `CMD_STEER_DIR` (signal moved to GPIO 17 on 2026-05-08 to remove the strap-pin risk from real signals). Reclaimable for any signal that is HIGH or high-Z at power-on. |
| 10 | 35 | 35 | HOLD | - | Octal-PSRAM pin. Internally reserved on the fitted N16R8 — unusable in practice. Kept as HOLD (not BLOCKED) because the layout also accepts a quad-PSRAM N8R2, where it would be free. |
| 11 | 36 | 36 | HOLD | - | Octal-PSRAM pin on N8R8 — same as Pin 10. (Was briefly assigned to CMD_REVERSE on 2026-05-02; moved to PCF8574 P0 on 2026-05-03 to restore N8R8 compatibility.) |
| 12 | 37 | 37 | HOLD | - | Octal-PSRAM pin on N8R8 — same as Pin 10. |
| 13 | 38 | 38 | HOLD | - | Unconstrained GPIO. Was `SDC_NOT_EMERGENCY` until 2026-05-08; signal moved to GPIO 18 (Pin 33) so Q3's gate driver could sit on the left side of the PCB next to the MOSFET. Currently free. |
| 14 | 39 | 39 | HOLD | - | Unconstrained GPIO. Earlier doc revisions described `SDC_ENABLE` here — that signal never existed in the schematic; the ESP32's contribution to the SDC chain is the GPIO driving Q3 directly (see Pin 33 / GPIO 18). |
| 15 | 40 | 40 | CMD_STEER_PWM | LEDC PWM | Steering motor PWM (Cytron H-bridge). |
| 16 | 41 | 41 | HOLD | - | Held for future CAN_RX (CAN currently moved to Orin carrier; medulla has no transceiver in this rev). |
| 17 | 42 | 42 | HOLD | - | Held for future CAN_TX (same as Pin 16). |
| 18 | 2 | 2 | HYDRAULIC_2 | ADC1_CH1 | Hydraulic pressure sensor 2 (input only) |
| 19 | 1 | 1 | CMD_STEER_PWM_IN (ex-PRESSURE_3) | PWM capture (MCPWM) | CN5.2. Retired as a pressure ADC input and repurposed to read the MT6701 steering-angle sensor's PWM output via MCPWM capture — see `km_sdir_pwm.h` and firmware's `#if`'d-out `PIN_PRESSURE_3` in `km_gpio.c`. Not an ADC channel; the old "Pressure sensor 3 (input only)" label was stale. |
| 20 | RX | 44 | BLOCKED | - | Owned by the dev-module's USB-UART bridge (UART0 RX0). Not reclaimable — the bridge IC drives this pin from the USB-C port of the DevKitC-1. |
| 21 | TX | 43 | BLOCKED | - | Same as Pin 20 — UART0 TX0, owned by the dev-module USB-UART bridge. |
| 22 | GND | - | GND | Power | Ground (top of right edge / RIGHT_HEADER pin 22) |
| 23 | 3V3 | - | 3V3 | Power | 3.3V supply (generated by S3 module LDO from 5V input) — top of left edge / LEFT_HEADER row 1 |
| 24 | 3V3 | - | 3V3 | Power | 3.3V supply |
| 25 | EN | - | RST | Reset | Reset (Espressif silkscreens this as `EN` for chip enable) |
| 26 | 4 | 4 | PEDAL_ACC | ADC1_CH3 | Accelerator pedal (input only) |
| 27 | 5 | 5 | PEDAL_BRAKE | ADC1_CH4 | Brake pedal |
| 28 | 6 | 6 | PRESSURE_1 | ADC1_CH5 | Pressure sensor 1 (input only) |
| 29 | 7 | 7 | PRESSURE_2 | ADC1_CH6 | Pressure sensor 2 (input only) |
| 30 | 15 | 15 | HOLD | - | Free and unassigned since 2026-08-08. It drove `SELECT_THROTTLE`, the SELECT pin of the U14 MAX4660 throttle mux; U14 was deleted from the schematic because a CMOS analog switch passes nothing while the board is unpowered (both channel MOSFETs are off), and because the kart's panel DPDT switch already selects the throttle source downstream on metal contacts that work unpowered. R32, the 10 kΩ pulldown on `SELECT_THROTTLE`, was deleted with it. No new function has been assigned to this pin. |
| 31 | 16 | 16 | MOTOR_HALL_1 | Digital In | Motor hall sensor 1 (moved from GPIO 37 for N8R8 compatibility) |
| 32 | 17 | 17 | CMD_STEER_DIR__3V3 | Digital Out | Steering motor direction (Cytron H-bridge). Moved here from GPIO 0 on 2026-05-08 to remove the BOOT-strap risk; now sits on the left side of the ESP32 alongside SDC_NOT_EMERGENCY. (UART1 TX default — but UART pins are remappable on ESP32-S3.) |
| 33 | 18 | 18 | SDC_NOT_EMERGENCY__3V3 | Digital Out | Drives the gate of Q3 (IRLZ44N) through R22 (100 Ω). When HIGH, Q3 conducts and pulls `SDC_IN_LOW_SIDE` to GND, completing the kart's SDC chain return path → no emergency. When LOW, Q3 is off and the SDC chain is broken → emergency. R23 (100 kΩ) gate-pulldown ensures Q3 is OFF (= emergency) at boot until firmware drives it HIGH. The signal name reads as the *intent* the ESP32 is asserting, not the chain's electrical state. Moved here from GPIO 38 on 2026-05-08 so the gate driver sits on the left side of the PCB next to the MOSFET. (UART1 RX default — remappable.) |
| 34 | 8 | 8 | SDA | I2C | I²C data — AS5600 steering angle sensor + PCF8574 I/O expander share this bus |
| 35 | 3 | 3 | BUZZER (old name) | Digital Out | Buzzer for debugging. Moved from GPIO 36 for octal-PSRAM compatibility. **Correction 2026-07-10:** this row used to claim "strap pin: JTAG src select, default high". Both halves are wrong on our hardware. (a) `STRAP_JTAG_SEL` eFuse is **not burned** (read from the chip), so GPIO 3 is never sampled as a strap. (b) GPIO 3 has **no internal pull at reset** — measured `IO_MUX_GPIO3 = 0x0a02` (neither FUN_WPU bit 8 nor FUN_WPD bit 7), against controls GPIO 0 = `0x0b02` (pull-up) and GPIO 45/46 = `0x0a82` (pull-down). It floats, so an external pulldown wins at boot. That makes GPIO 3 safe to drive a MOSFET gate — see the compressor reassignment in `history.md` 2026-07-10. |
| 36 | 46 | 46 | HOLD | - | Strap pin (ROM-print enable, flash/boot risk). Default LOW = no boot-message print, which is what we want. Reclaimable post-boot if signal's idle state is LOW at power-on. |
| 37 | 9 | 9 | SCL | I2C | I²C clock — same bus as SDA |
| 38 | 10 | 10 | HYDRAULIC_1 | ADC1_CH9 | Hydraulic pressure sensor 1 (input only) |
| 39 | 11 | 11 | MOSI | SPI | SPI data out (→ MCP4922 SDI). Also referred to as `OUT_SDI` in some parts of the schematic. |
| 40 | 12 | 12 | CLK | SPI | SPI clock (→ MCP4922 SCK). Also `OUT_SCK` in some schematic labels. |
| 41 | 13 | 13 | MISO | SPI | SPI data in. Unused by MCP4922 (write-only DAC); available for future SPI peripheral. |
| 42 | 14 | 14 | CMD_DAC_CS | SPI | MCP4922 chip select (active low). Also `OUT_CS` in some schematic labels. |
| 43 | 5V | - | +5V_USB | Power | 5V from USB VBUS via the medulla USB-C connector — powers the ESP32 dev board only (split-rail design, see history.md 2026-05-02). NOT connected to the L7805 +5V_REG rail. |
| 44 | GND | - | GND | Power | Ground (bottom of left edge / LEFT_HEADER row 22) |

## medulla-v2 pin allocation — decided 2026-07-31, as one table

Decided together rather than signal by signal, which is what let `PRESSURE_3` and `BUZZER` get
quietly repurposed on v1. Inputs to it: MT6701 stays on PWM, the MCP4922 stays as the throttle DAC,
and the op-amp keeps its 12 V rail (all Rubén, 2026-07-31).

**The constraint that drives the whole table: ADC1 is full.** On the ESP32-S3, ADC1 is GPIO 1–10 and
ADC2 is GPIO 11–20 — and ADC2 is unusable whenever WiFi is on, so in practice this board has exactly
**ten analog-capable pins**. v2 needs **seven** of them (`PEDAL_ACC`, `PEDAL_BRAKE`, `PRESSURE_1`,
`PRESSURE_2`, `PRESSURE_3`, `HYDRAULIC_1`, `HYDRAULIC_2`). All ten are currently occupied, four by
signals that are not analog at all: the steering-sensor PWM on GPIO 1, the compressor gate on GPIO 3,
and I²C on GPIO 8 and 9. Six analog + four squatters = ten, so restoring the third pressure channel
means evicting one squatter.

**Evict the steering sensor, not I²C.** Moving `STEER_SENS_PWM` from GPIO 1 to **GPIO 38** costs
nothing: GPIO 38 is an unconstrained HOLD today, is not a strap pin, is not on either ADC, and a PWM
capture input does not care which pin it sits on. That returns GPIO 1 to `PRESSURE_3`, its originally
designed use, and it is what `requirements.md` already asks for — the steering sensor gets a pin
chosen for it rather than inherited from a pressure channel. Moving I²C instead would work but
touches two pins and the firmware bus setup for no extra gain.

| GPIO | v2 signal | Why this pin |
|---|---|---|
| 1 | `PRESSURE_3` | ADC1_CH0. Returns to its designed use. |
| 2 | `HYDRAULIC_2` | ADC1_CH1, unchanged |
| 3 | `CMD_COMPRESSOR_PWM` | Unchanged, and deliberately: GPIO 3 floats at reset with no internal pull, so an external pulldown wins at boot. That is what makes it safe on a MOSFET gate. |
| 4 | `PEDAL_ACC` | ADC1_CH3, unchanged |
| 5 | `PEDAL_BRAKE` | ADC1_CH4, unchanged |
| 6 | `PRESSURE_1` | ADC1_CH5, unchanged |
| 7 | `PRESSURE_2` | ADC1_CH6, unchanged |
| 8 | `SDA` | I²C, unchanged. Costs an ADC1 pin but moving it buys nothing once the steering sensor has left. |
| 9 | `SCL` | I²C, unchanged |
| 10 | `HYDRAULIC_1` | ADC1_CH9, unchanged |
| 11 | `MOSI` | SPI to MCP4922, unchanged |
| 12 | `CLK` | SPI, unchanged |
| 13 | `MISO` | Unused — MCP4922 is write-only. Free pin, left as a spare. |
| 14 | `CMD_DAC_CS` | SPI chip select, unchanged |
| 15 | *free, unassigned* | Held `SELECT_THROTTLE` for the MAX4660 throttle mux until that mux (U14) was deleted from the schematic on 2026-08-08, together with its 10 kΩ pulldown R32. No replacement function is assigned. |
| 16 | `MOTOR_HALL_1` | unchanged |
| 17 | `CMD_STEER_DIR` | unchanged |
| 18 | `SDC_NOT_EMERGENCY` | Drives Q3's gate. Stays on a real pin — a safety read must not sit behind a bus transaction. |
| 21 | `MOTOR_HALL_3` | unchanged |
| 38 | **`STEER_SENS_PWM`** | **New.** MT6701 PWM angle capture, moved off GPIO 1. Unconstrained, no strap, not ADC. |
| 39 | *spare, reachable* | The remaining unconstrained GPIO, and genuinely unclaimed. `SDC_ENABLE` held a claim on it in earlier revisions; dropped 2026-08-01 — the shutdown loop is closed by Q3 off GPIO 18, and `SDC_ENABLE` was never a net. |
| 40 | `CMD_STEER_PWM` | unchanged |
| 41 | `CAN_RX` | Already reserved for CAN. Not ADC, not a strap pin. |
| 42 | `CAN_TX` | Already reserved for CAN. |
| 47 | `MOTOR_HALL_2` | unchanged |
| 0, 45, 46 | strap pins — leave HOLD | boot behaviour risk |
| 35, 36, 37 | unusable | octal PSRAM on the fitted N16R8 |
| 48 | BLOCKED | module's own RGB LED |
| 19, 20 | NC | USB pins, no connector on this board |

**No pin carries two signals, every strap pin is left alone, and the two ADC-capable pins spent on
non-analog signals (3 and 8/9) are spent deliberately.**

Two things this table does *not* solve, because they are connector capacity rather than GPIO
capacity: `SDC_ENABLE` still has no terminal to leave through, and CN4 gives the steering encoder its
two bus lines but neither power nor ground. See the connector audit in `tasks.md`.

**Firmware impact:** one pin number changes, `STEER_SENS_PWM` from GPIO 1 to GPIO 38. Everything else
keeps its current assignment.

## As-built pin use — board `84d6dd0`

**The table above is the *design*. This section is the *board that exists*, and it lists only the pins
whose real use differs.** Everything not listed here is used as the table says. Exceptions-only is
deliberate: a second full table would drift out of sync with the first one within a revision.

Physical modifications (cut traces, patch wires) are **not** here — they live in the per-board rework
list in [`../README.md`](../README.md), keyed to the same hash. This section is firmware-side pin
assignment; that one is copper. A person holding the board needs both.

| Pin | GPIO | Designed signal | Actual use on `84d6dd0` | Status |
|---|---|---|---|---|
| 19 | 1 | `PRESSURE_3` (ADC1_CH0) | **Reads the MT6701 steering-angle sensor's PWM output.** | Decided 2026-07-31 (Rubén). Pressure sensor 3 is not fitted on this board. |
| 35 | 3 | `BUZZER` (Digital Out) | **Drives the compressor MOSFET gate.** | Reassigned 2026-07-10 (see `../../../history.md`); and **permanent** — the kart carries no buzzer or ASSI at all (closed 2026-07-18; those are formula-vehicle only), so the `BUZZER` net name is historical. GPIO 3 floats at reset with no internal pull, so an external pulldown wins at boot — which is what makes it safe on a gate. |
| 13 | 38 | `HOLD` (unassigned) | **Planned:** raw ESP32 PWM → RC low-pass → U14 pin 8, as the throttle command, bypassing the SPI/MCP4922 path. | **Not done, and now obsolete.** It targeted the MAX4660 mux U14, which is fitted on this fabricated board but was deleted from the schematic on 2026-08-08 (a CMOS switch passes nothing unpowered, and the kart's panel DPDT switch already selects the throttle source downstream). The throttle command now leaves the board through the LM358 U1B gain stage instead. The 66 % shortfall this was meant to work around no longer exists: U1B now scales the DAC's 0–3.3 V up to 4.99 V before it leaves the board. |

Neither the pressure-3 sensor nor the buzzer is populated on this board, so both reassignments are
free — no signal was displaced. Record any further deviation here the day it is decided, not the day
the firmware is written; the point of this section is that someone probing the board can trust it.

## MCP4922 (dual 12-bit SPI DAC) — external chip connections on the PCB

| Pin | Signal | Connects to |
|---|---|---|
| VDD | +3V3 | 3.3 V rail. Moved from 5 V on 2026-08-01 (commit `16a35fb`): the MCP4922 datasheet DS22250A p7 sets VIH min = 0.7 × VDD, so a 5 V supply demanded 3.5 V on the SPI pins, which a 3.3 V ESP32 cannot reach. |
| VSS | GND | Ground |
| SHDN | +3V3 | Tied high (DAC always enabled) |
| LDAC | GND | Tied low → every SPI write latches to output immediately |
| CS | → ESP32 GPIO14 (CMD_DAC_CS) | |
| SCK | → ESP32 GPIO12 (CLK) | |
| SDI | → ESP32 GPIO11 (MOSI) | |
| VREFA | +3V3 via RC filter | 100 Ω series + 10 µF ceramic to GND, placed next to chip. Full scale on VOUTA is therefore 3.3 V. |
| VREFB | +3V3 via RC filter | 100 Ω series + 10 µF ceramic to GND (can share filter node). Full scale on VOUTB is therefore 3.3 V. |
| VOUTA | `CMD_ACC_ESP32__0_3V3` | Accelerator analog command, **0–3.3 V** at the DAC pin (U13 pin 14). It is amplified before leaving the board: U13 pin 14 → U1 pin 5 (LM358 U1B, +IN2), a non-inverting stage of gain 1.51 set by R37 5.1 kΩ and R38 10 kΩ, so full scale is **4.99 V** on U1 pin 7, which is the net `CMD_ACC__0_5V` and goes straight to CN10.1. This closes the earlier shortfall where a 3.3 V command reached only ~66 % of the motor controller's 0–5 V input range. |
| VOUTB | `CMD_PRES_DAC__0_3V3` | Pressure command, **0–3.3 V at the DAC pin**. It does not leave the board at that level: U1A (LM358) amplifies it ×3 (R19 2 kΩ / R20 1 kΩ) and CN10.2 exports **0–9.9 V** to the Festo VPPM proportional regulator. |

RC filter purpose: attenuates ~150 kHz switching ripple from the XW-1224 buck
by ~60 dB at the DAC reference pins. DAC VREF draws <100 µA so the 100 Ω
series resistor drops <10 mV (negligible vs 5V).

## Power architecture

```
Kart 12V battery ─┬─→ XW-1224 buck (external, 5A) ──→ 5V kart-wide rail
                  │                                   │
                  │                                   ├→ Medulla PCB 5V (H1.21)
                  │                                   │   │
                  │                                   │   ├→ ESP32-S3 module VIN ─→ module LDO ─→ 3.3V
                  │                                   │   └→ other on-board 3.3 V loads, including
                  │                                   │      MCP4922 VDD and its VREFA/VREFB filter
                  │                                   │
                  │                                   └→ other kart 5V loads
                  │
                  ├─→ L7805CDT linear regulator (U19, DPAK) ──→ the on-board +5V_REG rail.
                  │   THIS IS WHAT IS FITTED. Since the MAX4660 throttle mux U14 was deleted
                  │   from the schematic on 2026-08-08, this rail reaches only CN2 pin 3, plus
                  │   its own decoupling C3 (0.1 µF) and C4 (4.7 µF) — U14 was its only other
                  │   consumer. The MCP4922 (U13) moved to +3V3 on 2026-08-01 (commit 16a35fb).
                  │   The load is about 1 mA, 7 mW of heat, so a linear part is fine here. An
                  │   LM2596SX-ADJ buck (qty 8 in stock) was the alternative and was NOT taken;
                  │   settled 2026-07-31 against the schematic, where U19 = L7805CDT.
                  │
                  └─→ Cytron H-bridge 12V (steering driver) — permanently powered, NOT gated by
                      the manual/autonomous mode switch. Decision 2026-05-01: routing the Cytron
                      through the mode switch caused inrush brownouts on the Orin every time the
                      kart was switched to autonomous. See history.md (2026-05-01) for details.
                      The PCB only routes signals (CMD_STEER_PWM, CMD_STEER_DIR) to the Cytron,
                      not power. Firmware also commands PWM = 0 in manual — but that is a courtesy,
                      not the safety measure: the mode switch's second pole physically breaks the
                      cable from the Cytron to the steering motor in manual, so the motor is
                      disconnected regardless of what firmware does. Clarified 2026-08-08; the
                      earlier wording implied firmware was the only thing holding steering off.
```

## Manual/autonomous signal selection (throttle mux deleted 2026-08-08; I²C-driven reverse, decision 2026-05-01 / refined 2026-05-02 / brake-mux dropped 2026-05-08 / reverse moved to PCF8574 2026-05-03)

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

The throttle analog signal is no longer muxed on this board: the path is MCP4922 U13 pin 14 (VOUTA,
0–3.3 V) → U1 pin 5 (LM358 U1B, +IN2), a non-inverting stage of gain 1.51 set by R37 5.1 kΩ and R38
10 kΩ giving 4.99 V full scale → U1 pin 7, the net `CMD_ACC__0_5V`, straight to CN10.1
(net `CMD_ACC__0_5V`). Brake is **not** muxed either — manual mode does not need brake control routed
through the ESP32, so the brake signal goes straight from the MCP4922 to the motor
electronics with no switch. The digital reverse signal does not use an analog switch
either — it is driven by **U25 PCF8574T port P0** (I²C GPIO expander, pin 4)
wired in parallel with the manual reverse button (wired-OR via the motor
controller's existing pull-up). The PCF8574's quasi-bidirectional outputs are
natively open-drain with a weak internal pull-up, so the wired-OR is electrically
correct without any extra components. Steering is NOT muxed (ESP32 drives the
Cytron directly; PWM = 0 in manual mode).

See `~/dv/kart/kart-medulla/history.md` for the full design history — entries
`2026-05-01` (initial PCB-mux design), `2026-05-02` (reverse refinement to
open-drain on a direct ESP32 GPIO), `2026-05-03` (reverse moved off the ESP32
onto PCF8574 P0 to free GPIO 36 and gain N8R8 compatibility), `2026-05-08`
(brake mux dropped).

| Chip / signal | Type | Manual source | Autonomous source | Output |
|---|---|---|---|---|
| **LM358 U1B, ×1.51 non-inverting (throttle)** | analog 0–3.3 V in, 0–4.99 V out | (n/a — the pedal reaches the motor electronics through the kart's panel DPDT switch, not through this board) | MCP4922 VOUTA (U13 pin 14) = `CMD_ACC_ESP32__0_3V3` | U1 pin 5 → U1 pin 7 (**R37 5.1 kΩ / R38 10 kΩ, gain 1.51**) → CN10.1 (`CMD_ACC__0_5V`). **No mux on the PCB** since U14 was deleted on 2026-08-08; the panel switch chooses between this output and the pedal. |
| **LM358 U1A, ×3 non-inverting (pressure)** | analog 0–3.3 V in, 0–9.9 V out | (n/a — manual brake bypasses ESP32) | MCP4922 VOUTB = `CMD_PRES_DAC__0_3V3` | LM358 U1A (**R19 2 kΩ / R20 1 kΩ, gain 3** as of 2026-08-01, because U13 now runs from +3V3) → `CMD_PRES__0_10V` → CN10.2 → Festo VPPM. **No mux on the PCB** — the DAC always owns the command and the only way to release it is to write zero. |
| **U25 PCF8574T pin 4 / P0** | digital | Manual reverse button (in parallel) | I²C-controlled `CMD_REVERSE` (open-drain via PCF8574) | → kart-electronics-box REVERSE wire |

No ESP32 GPIO selects the throttle source any more. GPIO 15 drove the deleted
MAX4660's SELECT pin through the net `SELECT_THROTTLE`, and is now free.

`CMD_REVERSE` is asserted by writing to PCF8574 port P0 over I²C (same bus as
`SDA__I2C` / `SCL__I2C` on ESP32 GPIO 8 / 9, shared with the AS5600 steering
sensor). The PCF8574 P0 output is in parallel with the manual reverse button.
The motor controller's REVERSE input already has its own pull-up to 5 V (that
is why the button works by pulling the line LOW). Both the button and P0 can
only sink to GND, never push HIGH actively → wired-OR with no electrical
conflict. Fail-safe property: ESP32 or I²C bus dead → P0 stays high-Z (or in
its power-on default state, all outputs high) → only the button controls the
line (identical to the current manual-only setup).

**Firmware note**: `CMD_REVERSE` is set/cleared by writing the PCF8574 output
register over I²C. The PCF8574 is quasi-bidirectional, so writing `1` releases
the line (high-Z + weak pull-up), writing `0` pulls it LOW. No special "open-drain"
mode flag needed — the chip is built that way. There is no longer a direct ESP32
GPIO-mode constraint for CMD_REVERSE.

### GPIO assignments (current schematic)

Module variant in use: **WROOM-1-N16R8** (16 MB flash, 8 MB octal PSRAM) —
verified on hardware 2026-07-10. The ESP32 GPIOs involved in manual/autonomous source selection:

| Signal | GPIO | Notes |
|---|---|---|
| *none* | 15 | Free and unassigned. It drove `SELECT_THROTTLE` into the MAX4660 (U14) SELECT pin until U14 and its 10 kΩ pulldown R32 were deleted from the schematic on 2026-08-08. |
| `SDA__I2C` / `SCL__I2C` | 8 / 9 | I²C bus shared by AS5600 (steering angle) and PCF8574 (GPIO expander, drives `CMD_REVERSE` and EXP_P1..P7). |

`CMD_REVERSE` no longer consumes an ESP32 GPIO directly. With the PCF8574
indirection the design is fully N8R8-compatible — no signal depends on the
quad-PSRAM-only GPIOs (33-37).

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

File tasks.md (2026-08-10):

<!-- read in full — kept under 150 lines -->

# Tasks

The repo's cross-board task board, and the index of every other task board in the repo. Update status as you go: `TODO → In Progress → Done`. Read before editing; claim by adding `[YYYY-MM-DD <name>]` and the section change.

## Task boards
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

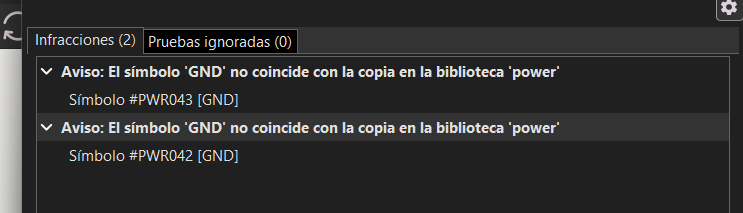
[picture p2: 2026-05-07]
.agents/image.png

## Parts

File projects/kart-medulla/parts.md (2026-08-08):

<!-- consult selectively — grep, never read in full -->

# Parts sourcing

Per-part provenance for symbols, footprints, 3D models, and datasheets used on this board. Add an entry whenever a new part is integrated. Datasheets themselves live in `datasheets/` per the convention in `datasheets/README.md`; this file just tracks where each artifact came from.

## MAX4660EUA+T (U14 — throttle SPDT mux) — NO LONGER IN THE DESIGN

**Removed from the schematic on 2026-08-08**, together with R32 (the 10 kΩ pulldown on
`SELECT_THROTTLE`) and C5 (U14's local 100 nF decoupling capacitor). Two reasons: it is a CMOS analog
switch, so with the board unpowered both channel MOSFETs are off and the driver's pedal was **not**
passed through — "normally closed" in the datasheet means closed at logic 0 with power applied, not
closed without power; and the kart's panel DPDT switch, downstream of this board, already selects the
throttle source on metal contacts that work with everything unpowered. The throttle command now runs
MCP4922 U13 pin 14 → LM358 U1B (gain 1.51) → CN10.1, with no analog switch in the path, and
GPIO 15 is free.

The part **is fitted on the fabricated v1 board**, so the sourcing details below are kept for anyone
working on that hardware.

- **Manufacturer:** Maxim Integrated (now part of Analog Devices)
- **Package:** 8-µMAX-EP (8-uSOP-EP)
- **Datasheet:** [`datasheets/MAX4660-MAX4662_Maxim_datasheet.pdf`](datasheets/MAX4660-MAX4662_Maxim_datasheet.pdf) — also at https://www.analog.com/MAX4660/datasheet
- **Symbol source:** project library (`kart-medulla.kicad_sym`, entry `MAX4660EUA_T`). Originally from EasyEDA-Pro export, ConvertEDA-migrated 2026-05-03. Pin numbering verified against SnapEDA-verified symbol on 2026-05-07. Not replaced — pin layout matches SnapEDA exactly, replacing would have broken existing wire positions.
- **Footprint source:** SnapEDA. Downloaded 2026-05-07 from https://www.snapeda.com/parts/MAX4660EUA%2BT/Maxim+Integrated/view-part/. File: `kart-medulla.pretty/SOP65P490X110-9N.kicad_mod`. Replaced the original ConvertEDA-migrated `UMAX-8_L3.0-W3.0-P0.65-LS4.9-BL-EP.kicad_mod` (still in the .pretty/ folder, unused).
- **3D model source:** SnapEDA (same download). File: `3dmodels/MAX4660EUA_T.step`.
- **Notes:** symbol has two pins both named "NC" — pin 2 is "Normally Closed" switch terminal (Passive), pin 5 is "No Connect" / do-not-wire (no_connect). See history.md 2026-05-07 entries for the full audit trail.
## LM358DR (U1 — pressure-command amplifier 0–3.3 V → 0–9.9 V, and throttle buffer)

- **Manufacturer:** Texas Instruments. Dual op-amp, SOIC-8. U1A is the non-inverting pressure-command stage, gain 3 set by R19 2 kΩ feedback and R20 1 kΩ to GND, taking MCP4922 U13 pin 10 (VOUTB, 0–3.3 V) and giving 9.9 V out. It was gain 2 with R19 = 1 kΩ until 2026-08-01 (commit `16a35fb`), when U13 moved from +5V to +3V3 and the lower full scale had to be made up in the gain; U1B is the non-inverting throttle stage, gain 1.51 set by R37 5.1 kΩ and R38 10 kΩ, taking MCP4922 U13 pin 14 (VOUTA, 0–3.3 V) in at U1 pin 5 and giving 4.99 V full scale at U1 pin 7, which is the net `CMD_ACC__0_5V` and reaches CN10.1 directly. A 1 kΩ series resistor R39 sat between the two until 2026-08-08; it existed only to limit current into the MAX4660's ESD diodes, so it was deleted when that part was.
- **Datasheet:** [`datasheets/LM358_TI_datasheet.pdf`](datasheets/LM358_TI_datasheet.pdf) — SLOS068AB, June 1976 rev. October 2024, covering LM158/158A/258/258A/358/358A/358B/358BA/2904/2904B/2904BA/2904V. Downloaded 2026-07-30 from https://www.ti.com/lit/ds/symlink/lm358.pdf. Also copied to the vault catalog at `~/dv/datasheets/LM358_TI_datasheet.pdf`.
- **The section that matters:** §5.7 "Electrical Characteristics: LM358, LM358A" — the plain LM358 grade, which is what `LM358DR` is. The B/BA grades in the same document have *different* specs (notably a 3 V–36 V supply range and much smaller output headroom), so reading the wrong table gives an over-optimistic answer.
- **Output swing from the positive rail** (§5.7, "OUTPUT" block): 2 V typ / **3 V max** at RL ≥ 10 kΩ; 4 V max at RL = 2 kΩ over 0–70 °C. The part is not rail-to-rail. On the board's +12 V rail this caps the guaranteed output at 9 V, below the 10 V the stage is asked to deliver. **Accepted, not a defect to fix on this board** — decided 2026-07-30, because the Festo VPPM regulates ~1 bar per volt and 9 bar of brake pressure is enough. Tracked for the next revision as "Give the pressure-command amplifier full 0–10 V swing on the next board revision" in `dv-hardware/projects/kart-medulla/tasks.md`; numbers and the firmware consequence are in the 2026-07-30 entry of `dv-hardware/history.md`.
- **Symbol source:** project library (`kart-medulla.kicad_sym`), split into a proper multi-unit symbol on 2026-05-04 during the ERC cleanup (it arrived from the EasyEDA-Pro export as a single flat symbol).

## MCP4922-E/SL — dual 12-bit SPI DAC (U13)

- **Manufacturer:** Microchip. Dual 12-bit voltage-output DAC, SOIC-14. Channel A is the throttle
  command (`CMD_ACC_ESP32__0_3V3`, into the LM358 U1B ×1.51 stage that drives CN10.1 — it fed the
  MAX4660 mux U14 until U14 was deleted from the schematic on 2026-08-08); channel B is the pressure command
  (`CMD_PRES_DAC__0_3V3`, into the LM358 ×3 stage). U13 runs from +3V3, so both outputs are 0–3.3 V.
- **Datasheet:** [`datasheets/MCP4922_Microchip_datasheet.pdf`](datasheets/MCP4922_Microchip_datasheet.pdf)
  — DS22250A, 2010, covering MCP4902/4912/4922. Downloaded 2026-07-31 from
  <https://ww1.microchip.com/downloads/en/DeviceDoc/22250A.pdf>.
- **Output swing** (§1.0 Electrical Characteristics, Output Amplifier): **0.01 V to VDD − 0.04 V
  typical**, with accuracy better than 1 LSb only between 10 mV and VDD − 40 mV. On this board VDD,
  SHDN# and both VREF pins sit on `+3V3` (moved there 2026-08-01, commit `16a35fb`), so full scale is
  about **3.26 V, not 3.30 V** — 1.2 % short. Tripled by the LM358 that is 9.78 V rather than 9.90 V,
  roughly 0.12 bar on a valve that regulates about 1 bar per volt. Negligible beside the op-amp's own 1–2 V of lost headroom, which is the
  binding limit on this chain.
- **Absolute maximum on the outputs** (§ Absolute Maximum Ratings): any input or output referred to
  VSS is **−0.3 V to VDD + 0.3 V**, so **−0.3 V to +3.6 V** here, and output-pin current is capped at
  **±25 mA**. This is the number behind the over-voltage concern on the old CN10.2 wiring: the **Festo
  VPPM-8L proportional pressure regulator** on the far end of CN10.2 is supplied from 24 V (its
  0–10 V setpoint is a separate signal), so a harness fault at that terminal presented roughly 20 V
  over the absolute maximum directly onto VOUTB, with no series resistor, clamp or buffer in the way. Moving CN10.2 to the
  op-amp output removed that path.
- **Two write-word bits are constrained by how VREF is wired** (Register 5-1, DS22250A page 24):
  - **`GA` must be 1**, which selects 1×. `GA` = 0 selects 2× and asks for 6.6 V out of a
    3.3 V-supplied part, which clips hard at ~3.26 V.
  - **`BUF` must be 0** (unbuffered VREF). Buffered mode accepts VREF only from 0.040 V to
    VDD − 0.040 V, and VREF here *is* VDD, which is outside that window. Unbuffered mode accepts
    0 to VDD, at 165 kΩ input impedance — fine driven from the 3.3 V rail.
- **Symbol source:** project library (`kart-medulla.kicad_sym`), from the EasyEDA Pro import.

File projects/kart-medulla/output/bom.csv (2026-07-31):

Reference | Value | Footprint | QUANTITY | DNP
C1,C5,C7-C13 | 100nF | kart-medulla:C0603 | 9
C2 | 0.33uF | kart-medulla:C0603 | 1
C3,C6 | 0.1uF | kart-medulla:C0603 | 2
C4 | 4.7uF | kart-medulla:C0603 | 1
CN1-CN10 | 2601-3103 | kart-medulla:TerminalBlock_WAGO_2601-3103_1x03_P3.50mm_Vertical | 10
Q3 | IRLZ44NPBF | kart-medulla:TO-220-3_L10.0-W4.5-P2.54-T | 1
Q4 | BSS123_C5184436 | kart-medulla:SOT-23_L2.9-W1.3-P1.90-LS2.4-BR | 1
R1-R3 | 1k | kart-medulla:R0603 | 3
R4,R6-R17,R31,R32,R35,R36,R38 | 10K | kart-medulla:R0603 | 18
R19 | 2K | kart-medulla:R0603 | 1
R20,R39 | 1K | kart-medulla:R0603 | 2
R22,R30 | 100 | kart-medulla:R0603 | 2
R23 | 100k | kart-medulla:R0603 | 1
R24,R26 | 2k | kart-medulla:R0603 | 2
R25,R27 | 3.9k | kart-medulla:R0603 | 2
R33,R34 | 4k7 | kart-medulla:R0603 | 2
R37 | 5.1K | kart-medulla:R0603 | 1
U1 | LM358DR | kart-medulla:SOIC-8_L5.0-W4.0-P1.27-LS6.0-BL | 1
U5 | SN74LVC3G17DCTR | kart-medulla:SOP65P400X130-8N | 1
U13 | MCP4922-E/SL | kart-medulla:SOIC-14_L8.7-W3.9-P1.27-LS6.0-BL | 1
U14 | MAX4660EUA+T | kart-medulla:SOP65P490X110-9N | 1
U19 | L7805CDT_C20611927 | kart-medulla:TO-252-2_L6.6-W6.1-P4.57-LS9.9-BR-CW | 1
U23 | SSW-122-01-T-D | kart-medulla:HDR-TH_ESQ-122-59-G-D | 1
U24 | SSW-122-01-T-S | kart-medulla:HDR-TH_ESQ-122-23-G-S | 1
U25 | PCF8574T/3,518 | Package_SO:SOIC-16_3.9x9.9mm_P1.27mm | 1

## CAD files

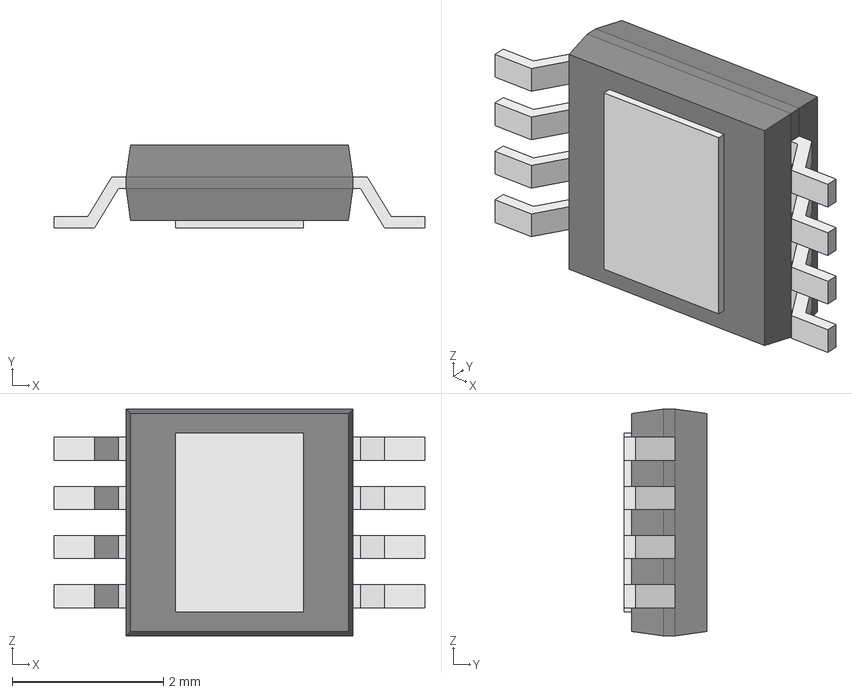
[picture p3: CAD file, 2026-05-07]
projects/kart-medulla/3dmodels/MAX4660EUA_T.step
4.91 x 1.10 x 3.00 mm
Body001 (Mirror #1) x 4

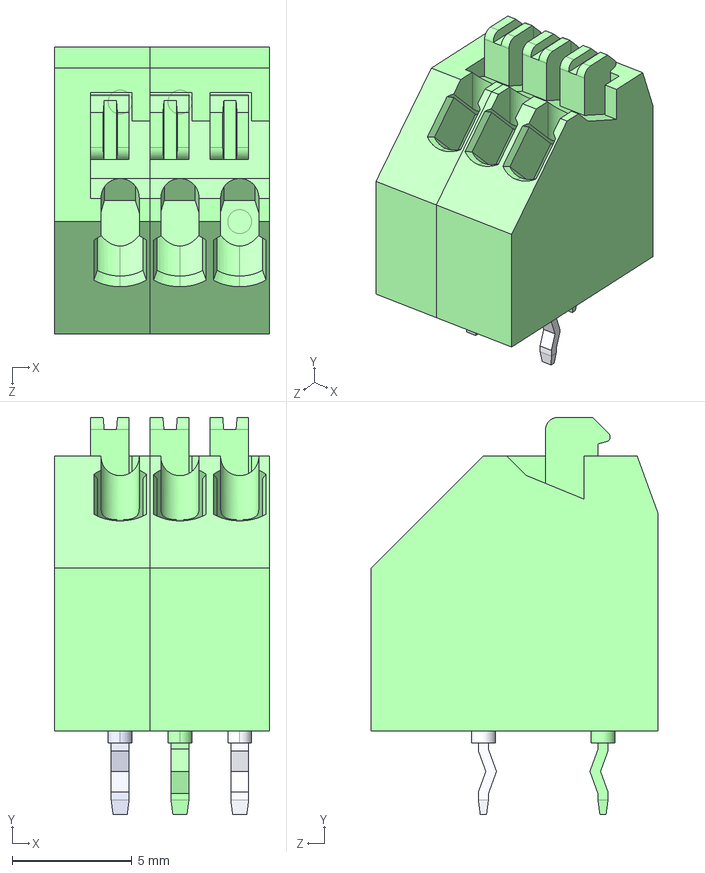
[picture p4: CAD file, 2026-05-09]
projects/kart-medulla/3dmodels/1990012_PTSA_3p_2.5mm.step
9.00 x 16.6 x 12.0 mm

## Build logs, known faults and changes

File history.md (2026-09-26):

<!-- consult selectively — grep, never read in full -->

# History

Append-only log. Chronological (oldest first), append at the end.

## 2026-05-03 — EasyEDA Pro → KiCad migration (kart-medulla)

**What worked:** [ConvertEDA](https://converteda.com) (free beta web service, drag-and-drop the `.epro`). Produced full KiCad 9-format project: 175KB `.kicad_pcb`, 251KB `.kicad_sch` (hierarchical, root + `_P1` sheet), 36 footprints in `kart-medulla.pretty/`. Validated openable by KiCad 10.0.1.

**What didn't work:**
- **KiCad 10.0.1 native importer** (`File → Import Non-KiCad Project → EasyEDA Pro`): silently produced empty stubs — 79-byte `.kicad_pcb`, 230-byte `.kicad_sch`. No error shown. Likely a format-version lag — the source `.epro` was exported by EasyEDA Pro **2.2.47.7** (per `editorVersion` in the unzipped `.epcb`) and the KiCad importer probably hasn't been updated for that version yet. The `.epro` itself is a valid zip with full content (verified manually).
- **`easyeda2kicad6`** (yaybee/easyeda2kicad6, npm): wrong tool entirely — converts EasyEDA **Standard** (old JSON format) → KiCad **6**. We need Pro → KiCad 10.
- **`easyeda2kicad.py`** (uPesy/easyeda2kicad.py, pypi): only fetches individual LCSC components by ID. Not a project converter despite the name.
- **KiCad per-file import path** doesn't exist for EasyEDA Pro `.esch`/`.epcb` files. `Import → Graphics` only takes DXF/SVG; the schematic editor has no per-file Pro importer. Project-level only.

**`.epro` internal format** (useful for future debugging):
- Zip archive containing `project.json` + 8 directories: `SHEET/`, `PCB/`, `SYMBOL/`, `FOOTPRINT/`, `INSTANCE/`, `POUR/`, `PANEL/`, `BLOB/`, `FONT/`.
- Schematic data in `SHEET/<uuid>/<n>.esch`, JSON-Lines (`["DOCTYPE","SCH","1.1"]\n["HEAD",...]`).
- PCB data in `PCB/<uuid>.epcb`, same JSON-Lines style.
- For single-sheet projects, `INSTANCE/` is empty — instances are inline in the `.esch`/`.epcb`.

**Naming + repo decisions:**
- Project folder named `kart-medulla` (matches `kart-medulla` firmware repo modulo case, and team verbal usage — `kart-brain` / `kart-medulla`).
- Single monorepo (`dv-hardware`) for all KiCad projects rather than per-project repos. Reasons: shared `lib/`, single onboarding clone, atomic cross-board changes, repo size is small (KiCad files are KB/MB).
- Visibility: **public** (matches existing UM-Driverless `kart_*` and `driverless` repos).
- Naming case: **kebab-case** chosen as team standard. Searched org for documented snake_case rule — none exists (the `kart_*` snake_case is just de facto from older repos).
- Original "ESP32 Expander" project (Jan 2026, EasyEDA) was renamed to "Kart Medulla (expander for ESP 32)" in May 2026 — same board. Old export kept in `easyeda-source/kart-medulla_2026-01-10_pre-rename.epro` as historical baseline.

**Post-conversion state (raw, not yet cleaned up):**
- ERC: 347 violations. Mostly `lib_symbol_issues` for absent `gen` lib (converter emits `lib_id "gen:CAP"` / `gen:Res` but doesn't ship the `gen` library), `power` lib mismatches (`12V`, `+5V_REG` not in KiCad's stdlib), and `footprint_link_issues` from missing `fp-lib-table`.
- DRC: 165 violations + 31 unconnected items. Will mostly resolve once footprint library is registered.
- **Cleanup deferred** — design is still in active flux (more green push-in connectors being added for expander chip GPIOs). No point cleaning ERC against a moving target. Revisit when schematic stabilizes.

**Gotchas hit:**
- KiCad 10's project-local `.history/` dir contains its own internal `.git/`. When committed naively, git treats it as a submodule pointer and the `.history/` gitignore rule does NOT apply. Fix: `git rm --cached projects/<x>/easyeda-source/.history`. Gitignore alone is insufficient once the embedded repo has been seen by git.
- **Gitignore trailing comments are NOT supported.** A line like `.history/  # KiCad local history` is interpreted as a literal pattern (the spaces and `#` become part of the pattern), so the rule silently does nothing. Comments must be on their own line. Verify any rule with `git check-ignore -v <path>`.
- Opening an `.epro` directly in KiCad creates sibling stub `.kicad_pcb` / `.kicad_pro` / `.kicad_sch` files in the same directory (sized 79 / 2 / 230 bytes — clear marker of failed conversion). Added blanket gitignore for `projects/*/easyeda-source/*.kicad_*` to prevent future contamination of source archives.
- `kicad-cli sch erc <file>` writes the report to **CWD by default**, not next to the input. Always pass `-o /path/to/report.rpt` explicitly to avoid littering the working directory.
- `kicad-cli` has no `import` subcommand — only `erc`, `drc`, `export`, `upgrade`. Headless EasyEDA conversion is not possible via KiCad CLI.

**Internal renames applied to ConvertEDA output** (it preserved the EasyEDA project name verbatim):
- Filenames: `Kart_Medulla_(expander_for_ESP_32).kicad_*` → `kart-medulla.kicad_*`, same for `_P1.kicad_sch` and `.pretty/` folder.
- Internal refs in `.kicad_sch` (`Sheetfile`, `project` blocks in instances), `.kicad_pcb` (title_block), `.kicad_pro` (`meta.filename`): same global string replace `Kart_Medulla_(expander_for_ESP_32)` → `kart-medulla`. Verified no stale refs remain (except the gitignored `.kicad_prl`).

---

## 2026-05-03 — Scripted schematic edits on kart-medulla (text-level, no KiCad GUI)

**What worked: pattern replication via direct s-expression edits.**

Tasks completed by writing s-expression blocks straight into the schematic file:
1. **Connector pin stubs** — added 8 wire+label pairs to empty pins on CN8/CN9/CN10 (push-in connectors with no wires from EasyEDA conversion). Wire length 36.83 mm leftward, matching the existing CN4-CN7 pattern. Labels named `<REF>_<PIN>_TODO` so user can grep for unrenamed ones.
2. **Sheet page resize** — A3 → A2 (one-line `(paper "A2")` change in both root and child `.kicad_sch`). Zero risk, no content moved.
3. **GPIO expander stub replication** — user added one stub on PCF8574 (U25) pin 13 INT#; we replicated the 21.59 mm pattern to other free pins.
4. **Connector column alignment** — moved CN8 by (-1.27, 0) and CN9 by (-2.54, 0) so all of CN7/CN8/CN9 share x=205.74. For each move, the connector + its 3 wires + 3 labels move as a unit (geometric coupling preserved).

**What did NOT work: free-form schematic design.** Adding new components, routing wires for new sub-circuits, deciding where connectors should live on the page — all GUI work. Programmatic placement produces overlap, ugly routing, broken visual conventions. KiCad IPC API (`kicad-python`) is for *modifying existing* schematic content, not creating new design layout.

**Lessons / gotchas:**
- **Pin "empty" detection requires checking ALL connection types**, not just wires:
  - regular `(label ...)` blocks
  - `(global_label ...)` and `(hierarchical_label ...)` blocks (different from regular labels — separate regex)
  - `(no_connect ...)` markers (pin intentionally unused — adding a wire there causes ERC errors)
  - Labels can be placed *directly on a pin attach point* with no intermediate wire (KiCad treats placement-on-pin as a connection)
  - Initial naive pass missed CMD_REVERSE (a hierarchical label sitting on U25 pin 5) and a `no_connect` marker on U25 pin 12. Resulting wires had to be removed in a follow-up edit. Always audit all four marker types before declaring a pin "empty".
- **Floating-point precision:** moving coordinates by deltas can introduce artifacts like `205.73999999999998` instead of `205.74`. KiCad tolerates these but they're ugly in diffs. Always round to 4 decimal places after coordinate arithmetic, then `:g`-format to drop trailing zeros.
- **KiCad rewrites file format on first open** after an external import: `generator` field changes (`easyeda_pro_to_kicad` → `eeschema`), whitespace/element ordering normalizes, version field bumps to KiCad's current. First post-conversion git diff is huge (thousands of lines, mostly cosmetic); subsequent diffs are small and meaningful. Don't be alarmed by the first big diff.
- **KiCad has no auto-reload of files modified externally**, and no `File → Reload from Disk`. If KiCad has the schematic editor open and the file is edited underneath, the next Ctrl+S in KiCad silently overwrites the external changes. Check for `~<projectname>.kicad_pro.lck` (project lock — held while launcher is open) AND `lsof` on the specific `.kicad_sch` (held only while the schematic editor window is open). Project lock alone doesn't mean the schematic is held — verify per-file.
- **Wire termination shortcut:** in KiCad eeschema, wire mode (`W`) is finished by **double-click** at the endpoint, NOT by Esc (Esc cancels the in-progress wire) and NOT by Enter (does nothing). Single-click on a pin/wire/junction also terminates cleanly.
- **`(at X Y)` in symbol blocks** has the rotation angle as a separate trailing integer for symbol instances (3 numbers), but for some other elements it's just X Y (2 numbers). Need separate regex patterns for both forms.
- **PCB footprint references** in `.kicad_pcb` use bare names (`"C0603"`) without library prefix when the project has a local `<projectname>.pretty/` folder — KiCad auto-discovers it if the folder name matches the project name.

**Pattern that's safe to script:** geometric translation/replication where you have:
1. Existing data to copy (length, direction, format)
2. Known target coordinates that are grid-aligned
3. No spatial design judgment required (placement decisions inherited from existing elements)

**Pattern that's NOT safe to script:** anything that requires deciding "where should this go visually" — symbol placement on an empty area, wire routing around existing elements, label placement that doesn't follow from a clear pattern.

**Two more bugs hit on day 2:**

1. **Y-flip between symbol library and schematic instance coordinates.** KiCad's `lib_symbols` use Y-up convention (paper-schematic legacy: positive Y = up the page). When a symbol is INSTANTIATED in a schematic, KiCad applies an automatic Y-flip — schematic coords are Y-down. Initial pin-position calculations did NOT apply the flip, so PCF8574T pin numbering was inverted vertically: my "P0" stub landed on P1, my "P7" stub landed on INT#, etc. The symptom: the user opens the file and sees `EXP_P0_TODO` sitting next to "P1" on the chip. Fix: world_y = symbol_y - lib_pin_y (NOT +). Verify by cross-referencing one known wire (e.g., the user-added stub's known coordinates) against your computed pin positions BEFORE doing pattern replication based on those coords.

2. **Labels are NOT always exactly at wire endpoints.** EasyEDA-converted schematics have label positions that are sometimes 1.27 mm offset from the wire's geometric endpoint (probably because EasyEDA stores label-anchor differently from KiCad). When moving a connector + wires + labels as a unit, a tight tolerance (0.05 mm) won't catch labels that are positioned slightly inside the wire. Symptom: connector and wires move, labels stay, wires now visually disconnected from labels (functionally still fine if the label connects-by-name elsewhere, but ugly and easy to misread as a broken net). Fix attempts: (a) use bigger tolerance (~2 mm) when looking for labels at wire endpoints; (b) for moves that include real-signal labels (not TODO placeholders), revert and do the move in eeschema GUI instead. Detected by ERC violation count jumping by ~3 per affected wire (single-endpoint warnings appear).

**On Y-alignment of converted connectors:** the right-side connectors (CN7-CN10) are 1.27 mm above the left-side row positions. Aligning them programmatically tripped the label-offset bug above (CN1-CN4 labels are EasyEDA-style offset from their wires). Reverted; left as a GUI task. Safe scriptable alignment was limited to X-column alignment of CN7/CN8/CN9 where all the labels were freshly-added TODO labels at exact wire endpoints.

**The Y-flip applies to connector symbols too, not just chips.** Reflex was to think the lib-vs-schematic Y-flip was a chip-pin-specific gotcha, but it's universal — every symbol's pin coords need it. For the 1990012 push-in connector: lib has pin 1 at y=+2.54 (top in lib coords), pin 3 at y=-2.54 (bottom). After the flip, world pin 1 is at center_y - 2.54 (smaller y, top of screen), pin 3 at center_y + 2.54 (bottom). Earlier connector code used `y + 2.54` for pin 1, which was wrong — the wires/labels still attached correctly because pin attach POINTS were computed for all 3 pins and the symmetry hid the bug, but pin number reporting in commit messages was inverted. Always sanity-check pin numbering against a known reference (e.g., open the schematic, see which pin number the top-most wire belongs to).

**Adding a power symbol via text edit requires THREE places to update:**
1. The symbol-instance `(at X Y angle)` in the symbol header
2. The `(property "Reference" "#PWRnn")` block (the *property* reference)
3. The `(instances ... (path "..." (reference "#PWRnn")))` sub-block (the *instance-path* reference)

Items 2 and 3 must match. KiCad uses the instance-path reference (item 3) for display; if you only update item 2, ERC and the GUI both still show the template's old reference number. Symptom: a fresh `#PWR36` symbol appears in ERC reports as `#PWR08` (the number from whatever symbol you copied as a template). Always grep for any leftover stale ref numbers after copying a symbol block.

---

## 2026-05-04 — KiCad no_connect marker semantics (corrected)

The `(no_connect)` flag (the small "X" placed on a pin in the schematic editor) means **"the designer intentionally chose not to wire this pin to anything external on this board"**. It silences ERC's `pin_not_connected` warning by declaring the omission deliberate.

It does **not** mean:
- The pin doesn't physically exist on the package
- The pin is internally disconnected on the silicon
- The pin is a manufacturer-designated NC pad

Source: KiCad eeschema docs (master) — "No-connection flags are used to indicate that a pin is intentionally unconnected. These flags prevent 'unconnected pin' ERC warnings for pins that are intentionally unconnected." (https://docs.kicad.org/master/en/eeschema/eeschema.html)

Practical implication: any unused pin can carry a `no_connect` marker, including real-but-unused pins like the second op-amp on a dual op-amp (LM358 pins 5/6/7 when only op-amp A is used). For digital chips, NC markers are fine. For op-amps specifically, tie-back wiring (unity-gain follower with input held at a fixed voltage) is the better engineering practice — prevents the floating amplifier from oscillating or coupling noise — but NC markers are valid and ERC-clean.

Don't conflate the schematic-level `(no_connect)` marker (board-specific intent, common) with a symbol pin's `no_connect` electrical type (part-designer's intent that the pin should never be wired, used in symbol definitions for reserved/NC pads). Both silence ERC; the schematic marker is the more frequent tool.

---

## 2026-05-04 — `unconnected_wire_endpoint` requires terminating the wire's geometric endpoint, not just the net

A label sitting *mid-wire* still connects the label's net to the wire (KiCad uses the label's `(at)` point, not the wire's ends, for net assignment). But the wire's geometric endpoints are a separate ERC concern: if a wire endpoint sits in empty space — not on a pin, not at a label's `(at)` point, not at another wire/junction — ERC fires `unconnected_wire_endpoint` even though the net is logically named. Place labels at the wire endpoint (or shorten the wire to end at the label) so the geometry and the electrical termination coincide.

Mental model: ERC checks two things separately. (1) Does the *net* have at least the right kind of pins on it? (2) Does each *wire* have its endpoints terminated by something that "anchors" it (pin, label, junction, other wire)? Mid-wire labels satisfy (1) but not (2).

---

## 2026-05-07 — MAX4660 (U14) symbol audit: false alarm on pin numbers, real bug on electrical types

**Trigger:** User noticed two pins on U14 (MAX4660 SPDT throttle mux) both labeled "NC" with red X markers in the symbol drawing. Asked which one is the actual no-connect.

**Initial finding (correct):** The symbol has two `NC` labels — pin 2 is "Normally Closed" (the SPDT default-throw signal terminal, wired to `PEDAL_ACC__0_5V`) and pin 5 is the package's "No Connect" (no internal die connection). The schematic itself correctly places a no-connect flag on pin 5. The red X on pin 2 in the symbol drawing comes from the pin's *electrical type* being set to "Unconnected" — which is wrong, it should be Passive. Same issue may apply to pin 7 (V−) which also drew with an X in the symbol editor.

**Wrong escalation (then corrected):** I claimed the symbol's pin *numbers* were also shuffled vs. datasheet — basing this on a WebSearch snippet that decoded the Maxim datasheet pinout caption as `1=IN 2=N.C. 3=GND 4=COM 5=NC 6=V- 7=NO 8=V+`. I pre­sented a scary table showing the schematic would put +5V on COM, signal on V+, etc. Catastrophic-sounding but **not verified against the actual datasheet**.

**Disconfirmation:** User asked for a proper downloaded symbol. SnapEDA `MAX4660EUA+T` (SnapEDA-verified) has pin numbering: `1=COM 2=NC 3=GND 4=V+ 5=NC 6=IN 7=V- 8=NO 9=EPAD` — **identical to the original EasyEDA-converted symbol**. SnapEDA validates parts, so the correct pinout is the SnapEDA/original one, not my WebSearch interpretation. My pin-shuffling claim was wrong.

**Real status of original symbol:** Pin numbers correct. Electrical types wrong on pins 2 and 7 (drawn with X). No physical wiring danger; just an ERC and clarity issue.

**Lesson:** WebSearch snippets that "decode" a pinout caption from a position-list string are unreliable; do not present them as verified facts. SnapEDA-verified symbols and the existing project symbol agreeing with each other is much stronger evidence than a single search snippet. When two independent sources agree against my reading, retract before escalating.

**Migration context:** This symbol came in via the EasyEDA-Pro → KiCad migration (ConvertEDA, May 2026). The conversion preserved pin numbers and labels but mis-set electrical types, which is the actual EasyEDA-conversion artifact here — not pin shuffling.

**Download workflow note:** SnapEDA, Component Search Engine (Samacsys), Ultra Librarian all gate KiCad downloads behind login walls. Programmatic curl/WebFetch fails. User pointed out I could have driven their logged-in Chrome with `osascript` — viable next time, since global rules confirm Chrome has "Allow JavaScript from Apple Events" enabled. SnapEDA download did not actually require an account in this instance per the user.

**Verified MAX4660 8-pin µMAX pinout (from SnapEDA-verified symbol; matches original project symbol):**
```
1: COM    8: NO
2: NC     7: V-
3: GND    6: IN
4: V+     5: NC (no internal connection)
9: EPAD (thermal pad)
```

---

## 2026-05-07 — MAX4660 (U14) integration: SnapEDA footprint+3D adopted, hidden wire-disconnect bug found and fixed

**Symbol correctness summary (the part that confused things):**
- SnapEDA-downloaded symbol (`MAX4660EUA_T.kicad_sym` from the zip): **correct**.
- Project library symbol (entry inside `projects/kart-medulla/kart-medulla.kicad_sym`): **also already correct** (pin 2 = passive, pin 5 = no_connect).
- Cached copy inside the schematic file (`lib_symbols` block in `kart-medulla_P1.kicad_sch`): **wrong** — pin 2 = no_connect (a stale snapshot from an earlier broken symbol version).

KiCad renders symbols from the schematic's cached copy, not the library — so the symbol editor showed the broken cache, even though the library was fine. Running `Tools → Update Symbols from Library` would have fixed it. **SnapEDA was not needed to fix the symbol** — the library already had the right one. SnapEDA's actual contribution to this integration was the verified **footprint** (`SOP65P490X110-9N.kicad_mod`) and **3D model** (`MAX4660EUA_T.step`), plus confirmation that the existing pin map was correct.

After confirming the original symbol's pin numbers were correct (matched SnapEDA), did a full SnapEDA integration for U14 (MAX4660 throttle mux). Workflow:

1. User downloaded `MAX4660EUA_T.zip` from SnapEDA without needing an account (so the SnapEDA login wall reported earlier wasn't actually blocking — should have tried first).
2. Extracted: symbol `MAX4660EUA_T.kicad_sym`, footprint `SOP65P490X110-9N.kicad_mod`, 3D model `MAX4660EUA_T.step`.
3. Copied footprint into `projects/kart-medulla/kart-medulla.pretty/`.
4. Created `projects/kart-medulla/3dmodels/` and put `MAX4660EUA_T.step` there. (First 3D model in the project — no prior convention; chose `${KIPRJMOD}/3dmodels/` as the standard location.)
5. Added `(model "${KIPRJMOD}/3dmodels/MAX4660EUA_T.step" ...)` to the new footprint.
6. Updated `kart-medulla.kicad_sym` U14 symbol's default Footprint property → `kart-medulla:SOP65P490X110-9N`, Datasheet → analog.com.
7. Updated U14 instance in `kart-medulla_P1.kicad_sch` (Footprint + Datasheet override).
8. **Critical fix:** the cached `lib_symbols` copy of `MAX4660EUA_T` in `kart-medulla_P1.kicad_sch` had pin 2 (NC) marked as electrical type `no_connect` — wrong; the library copy in `kart-medulla.kicad_sym` correctly had `passive`. The cache had drifted from the library, and KiCad uses the cache, so the schematic editor was rendering pin 2 with the no-connect-X marker. Patched the cache to `passive`.
9. **Real bug uncovered:** with pin 2 fixed, ERC immediately fired `pin_not_connected` on U14 pin 2. Investigation showed the `PEDAL_ACC__0_5V` wire ended at x=375.92 but pin 2's connection point is at x=384.81 — an 8.89 mm gap. The wire **never actually reached pin 2**. The broken `no_connect` pin type had been silencing this ERC violation by making the pin a legal "no connect" terminal. So the throttle mux's default-throw input (sensor pedal value passing through to the motor) was not wired at all in the schematic. Extended the wire's endpoint to (384.81, 217.17) to close the gap. ERC now reports 0 errors.

**Lesson:** When ERC suddenly flags a violation after a "cosmetic" symbol fix, **the symbol bug was likely concealing a real schematic bug**. `no_connect` and similar permissive pin types act as ERC-silencers; using them inappropriately hides genuine wiring errors. Cache-vs-library drift is a known KiCad failure mode — `Tools → Update Symbols from Library...` would have surfaced this earlier.

**Files changed:**
- `kart-medulla.kicad_sym`: U14 entry — Footprint and Datasheet properties populated.
- `kart-medulla_P1.kicad_sch`: cached `MAX4660EUA_T` symbol pin 2 type `no_connect → passive`; U14 instance Footprint and Datasheet updated; `PEDAL_ACC__0_5V` wire extended from 375.92 → 384.81 to actually reach pin 2.
- `kart-medulla.pretty/SOP65P490X110-9N.kicad_mod`: new footprint with 3D model reference.
- `3dmodels/MAX4660EUA_T.step`: new (folder created).

**Verification:** `kicad-cli sch erc --severity-error` → `Found 0 violations`. Paren-balance check on all edited files passes.

---

## 2026-05-07 — kicad-mcp-pro installed; pins 20/21 (UART0 TX0/RX0) NC'd on kart-medulla

**Tooling change:**
- `kicad-cli` symlinked to `/opt/homebrew/bin/kicad-cli` (was buried inside `/Applications/KiCad/KiCad.app/Contents/MacOS/`). Reports KiCad 10.0.1.
- `kicad-mcp-pro` v3.1.8 installed via `pipx --python /opt/homebrew/bin/python3.14` (the package needs Python ≥3.12; the user's default `python3` is 3.11 from a platformio venv). Registered in Claude Code at user scope: `claude mcp add kicad -s user -- /Users/rubenayla/.local/bin/kicad-mcp-pro --transport stdio --profile agent_full`. MIT-licensed despite the "Pro" name. Other contenders considered: `lamaalrajih/kicad-mcp` (lighter, KiCad 7+), `Seeed-Studio/kicad-mcp-server` (39 tools, targets KiCad 9), `mixelpixx/KiCAD-MCP-Server`. Picked the Pro one because it's the only one that explicitly supports KiCad 10.

**Design change applied:**
- Header pins 20/21 of the ESP32-S3-DevKitC-1 footprint on `kart-medulla_P1.kicad_sch` are GPIO 44/43 = RX0/TX0 = UART0. Previously rendered as global labels `TX0` / `RX0` with single-pin wires going nowhere. Confirmed via grep that nothing on the medulla PCB or in `~/dv/kart/kart-medulla` firmware references these nets. They are nonetheless reserved by the dev board's on-board CP210x USB-UART bridge (which physically drives those module pins whenever the UART USB-C is plugged in) — so they must not be reassigned on the medulla side either. Fix: removed the global labels + their wires, added `(no_connect)` markers at the pin endpoints (389.89, 48.26 / 50.8), and added `(text)` annotations explaining the reservation. Commit `b07c56f`.

**Gotchas hit (now also rules in AGENTS.md):**
- **kicad-mcp-pro caches the schematic in memory** between calls. After `kicad_set_project`, the next MCP write call (`sch_add_no_connect`, etc.) flushes the cached copy to disk, silently overwriting any direct-file edits made between MCP calls. Symptom: `git status` shows zero changes after multiple "successful" Edit calls. Fix: pick one workflow per session — pure-MCP or pure-file-edit, never interleave. KiCad open in the GUI is *fine* if you only reload (File → Revert) and never save before the agent commits; KiCad itself only writes on explicit save.
- **`agent_full` MCP profile** is missing `sch_delete_label` and `sch_add_text`. So "replace a global label with a text annotation" must be done by direct file edit. Filed mentally as a feature gap.
- **`sch_add_no_connect` snaps to 2.54 mm by default.** Header pins on the official ESP32-S3-DevKitC-1 sit on 1.27 mm offsets (x=389.89). Marker landed 1.27 mm off; fix: pass `snap_to_grid=False`.

---

## 2026-05-07 — Idea: agent works in a separate git worktree so user can keep KiCad open

**Problem context:** Twice today the agent's edits to `kart-medulla_P1.kicad_sch` were silently clobbered — once by KiCad's stale-buffer save, once by interleaving direct file edits with kicad-mcp-pro writes. Root cause is that the agent and the user's KiCad are racing for the same on-disk file.

**Idea (not yet implemented; user said note it, don't set up):** add a sibling worktree just for agent work.

```
~/repos/dv-hardware/         user's main worktree, KiCad stays open
~/repos/dv-hardware-agent/   agent's worktree, on branch agent/<topic>
```

Setup is `git worktree add ../dv-hardware-agent agent-work`. Agent points the MCP at the worktree's project path with `kicad_set_project /Users/rubenayla/repos/dv-hardware-agent/projects/<board>` and edits there. KiCad's `${KIPRJMOD}` resolves relative to the worktree's `.kicad_pro`, so symbol libs (`*.kicad_sym`), footprint pretties (`*.pretty/*.kicad_mod`), and 3D models (`3dmodels/*.step`) all work without re-pathing. Agent commits + pushes on its branch; user pulls into their worktree when ready and runs `File → Revert` in KiCad to pick up the changes.

**Trade-offs to remember if/when this gets set up:**
- KiCad files are text but not line-mergeable. Concurrent edits to the *same* `.kicad_sch` or `.kicad_pcb` in both worktrees → ugly manual merge (KiCad re-formats huge sections on save, so even small logical changes can collide on hundreds of lines). Coordinate by topic — agent on one feature branch per task, user avoids touching the same file.
- The MCP is a single process. `kicad_set_project` per session is enough; no reconfig of the MCP itself.
- Could be wrapped in `~/.claude/skills/dv-worktree/SKILL.md` so the agent can spin one up on demand.

---

## 2026-05-07 — KiCad ERC: "Input pin not driven" on GND net (kart-medulla GPIO expander U25 A0)

### Problem
ERC error: `Symbol U25 Pin 1 [A0, Input, Line] — Input pin not driven by any Output pins`. A0 of the PCF8574T (I2C address pin) was tied to GND for address 0, but ERC kept failing. Took many iterations to diagnose because of multiple overlapping KiCad concepts that all *look* the same to a human.

### Root causes (compound)
1. The "GND" on A0 was a **global label** (the arrow shape, `Ctrl+L`), not a **GND power symbol** (the triangle, `P`). They share the name "GND" but live on **separate nets**. ERC does not auto-merge them.
2. Even after using the correct GND **power symbol**, ERC still complained because the **GND power symbol's pin is type Power Input**, not Power Output. A net with only Power Input pins has no driver → ERC error.
3. Fix for #2 is **PWR_FLAG** — a special symbol whose pin is type Power Output, exists exclusively to tell ERC "this rail is actually driven." Need exactly **one** PWR_FLAG per power net **across the entire design** (one for GND, one for +3V3, etc.). Two PWR_FLAGs on the same net = "Power output and Power output connected" error.

### Key facts to never re-derive
- **Global label "GND" ≠ GND power net.** Labels are just net names. Power symbols carry power-net semantics.
- **Power symbols all named "GND"** (the triangles) **share one global net** across all sheets, regardless of where placed. So one PWR_FLAG drives every GND triangle in the project.
- **Global Label "Shape" property** (Input/Output/Bidirectional/Tri-state/Passive) is **purely cosmetic** — only changes the arrow shape. Does not affect ERC electrical type. ERC drive checks look at *symbol pin types* and PWR_FLAG, never at label shapes.
- **Pin types that DRIVE a net for ERC purposes:** Power Output, Output, PWR_FLAG. Power Input does not drive (this is why GND/+3V3 power symbols alone don't satisfy ERC).
- KiCad shortcuts: `L` = local label (sheet-scoped), `H` = hierarchical label, `Ctrl+L` = global label (the arrow), `P` = power symbol (the triangles, GND/+3V3/etc.).

### Recipe to make a power net pass ERC
1. Place GND power symbol (`P` → GND) on every GND-bound wire. Make sure the pin tip lands on the wire endpoint with a green junction dot.
2. Place exactly **one** PWR_FLAG (`P` → PWR_FLAG) somewhere on the GND net. Conceptually next to the actual power source (e.g., ESP32's GND pin) is fine, but electrically it doesn't matter.
3. Repeat (#2 only) for +3V3, +5V, etc.

### Confusion to avoid next time
- Do not suggest "the wire is floating" or "no junction" without verifying — the user can see the schematic and that gaslights them. The error is almost always a **net semantics** issue (label vs. power symbol vs. missing PWR_FLAG), not a literal disconnection.
- Trust the user when they say "I already placed the power symbol" — verify by checking PWR_FLAG count and pin-to-wire snap, not by re-explaining the difference between symbols.
- The KiCad GND power symbol can appear rotated (pointing left, right, down) — it is still the same symbol. Don't mistake a rotated GND triangle for an arrow-shaped global label.

### Resolution
User fixed it by placing **three separate GND power symbols, one per pin (A0, A1, A2)**, instead of wiring all three pins together to a single shared GND symbol. ERC then passed (0 violations).

### Why three-symbols-works when one-symbol-wired-to-all-three didn't (NOT FULLY EXPLAINED)
Electrically these should be identical: all three pins on the global GND net via the PWR_FLAG elsewhere. Power symbols with the same name (`GND`) merge into one global net regardless of how many copies are placed. **No confirmed root cause** for why the single-symbol version failed ERC on A0 specifically.

Most likely candidate (unverified): a hidden wire-connectivity issue where A0's pin or one wire segment was off-grid / not actually joined to the rest. ERC's "Input pin not driven" fires when a net has only Input-type pins and no driver — *including* the case where the "net" is just one pin with nothing else on it (a one-node net counts as undriven). That would explain why A0 alone failed while A1/A2 passed. But the user did not visually confirm a misalignment, so this remains a hypothesis.

### Lesson for future ERC drive errors
If ERC says "Input not driven" on **one specific pin** when adjacent pins on what looks like the same wire are fine: try dropping a power symbol directly on the offending pin (bypass the wire). If that fixes ERC, the wire connectivity was the issue. If not, there's something else going on — inspect the .kicad_sch file via MCP rather than guessing.

### Final final
- One PWR_FLAG per power net across the whole design (not per sheet, not per symbol). On disk this project has `#FLG01` (GND), `#FLG_+3V3`, `#FLG_+5V_USB01`, `#FLG_+12V01`. Don't add more.
- The kicad MCP (`mcp__kicad__run_erc`, `grep PWR_FLAG <sch>`) reads disk and is far faster than iterating from screenshots.

---

## 2026-05-07 — Decision: stay on KiCad long-term (vs EasyEDA)

Revisited tool choice after MCP-related friction. Decision: **KiCad**, long-term.

Reasoning:
- Open format, local files, git-tracked — work is owned, not hosted on a vendor's servers.
- No vendor lock-in; portable across fabs (not tied to JLCPCB pipeline).
- Scriptable; MCP tooling is improving and recent ERC issues were all resolved within KiCad.
- EasyEDA is fine for quick JLC-bound boards but wrong foundation for hardware meant to live for years.

---

## 2026-05-07 — Git workflow: rebase-on-pull when both sides made identical changes to the same file

Situation: peer pushed commit `d0f64d1 "pcb update"` (touched `.kicad_pcb` + 1 line of `.kicad_pro`). Local had uncommitted edits including the **same 1-line change** to `.kicad_pro` (KiCad GUI clears `used_designators` automatically) plus schematic + agent-doc edits.

**Resolution path that worked cleanly:**
1. Commit local work first (split into logical commits) — gives a checkpoint to return to if anything goes wrong.
2. `git pull --rebase` — replays local commits on top of peer's. Identical `.kicad_pro` change auto-resolved with no prompt.
3. Push.

**Why `--rebase` over plain `git pull`:** plain pull creates a merge commit for trivial 1-commit divergences (noisy). Rebase produces linear history `peer → you`. Local commits get new SHAs (parent changed) — safe because they weren't pushed yet. Never rebase already-pushed commits.

**Recovery levers if rebase goes wrong:** `git rebase --abort`, `git reflog` + `git reset --hard <sha>`. Commits are nearly impossible to lose once made.

---

## 2026-05-07 — Parallel work on a single KiCad PCB: not really viable

Question: can two+ people work on different regions of the same `.kicad_pcb` in parallel without merge conflicts?

**Short answer: no, not on a shared `.kicad_pcb`.** Reasons:
- `.kicad_pcb` is one monolithic S-expression file. Footprints, tracks, vias, zones are flat lists.
- KiCad's save serialization is **not order-deterministic** between sessions, so even non-overlapping spatial edits can produce diff hunks git can't auto-merge cleanly.
- Global state (net classes, design rules, stackup, board outline) is shared — any edit there forces a manual merge.

**What works:**
- **Schematic ↔ PCB split** (different files). What we're doing now — Rubén on schematic + docs, peer on PCB. Trivially parallel.
- **Multi-board projects** — split logically into separate KiCad projects (e.g. main board + sensor adapter). Each is its own file set.
- **Time-sliced single-writer** via the `tasks.md` claim pattern. Boring but reliable.

**What sort-of works:** spatial division + serialized merges (A: top quadrant, B: bottom). Second person rebases and copies changes manually. Painful at >2 people.

**What doesn't exist in stock KiCad:** real-time multi-user editing or per-region locking. (Altium 365 / OrCAD X have it; KiCad doesn't.)

**Recommendation for this team:** keep the schematic/PCB split. Third person → give them a separate sub-board as its own project, not a chunk of medulla.

---

## 2026-05-07 — Investigated KiCad-AI workflow problems; added workflow doc + guard; tested kicad-sch-api

**Trigger:** Recurring failures in error log (MCP cache clobbering edits, KiCad GUI auto-saving over agent commits, hand-rolled netlist parsers, screenshots-instead-of-MCP loops). User asked for a real fix.

**Root structural finding:** KiCad has no official IPC API for the **schematic editor** as of KiCad 10. PCB has `kicad-python` (works with running KiCad), schematic does not. Every schematic-editing MCP server (kicad-mcp-pro, Seeed-Studio, lamaalrajih, circuit-synth) is doing raw S-expression manipulation. That is the source of all our caching/conflict pain — these are not bugs in any one server, they're a structural limit until KiCad ships schematic IPC (KiCad 11+).

Seeed-Studio docs put it explicitly: *"KiCad must be closed and reopened to see file changes (no hot-reload). Use KiCad GUI for design work. Use this MCP server for analysis, validation, and code generation."* Adopted as our default.

**What was added:**
- `kicad-workflow.md` — codifies two modes: (A) read-only MCP, KiCad GUI may be open, default 90% of the time; (B) direct-edit, KiCad closed, no MCP writes that session. With tool-selection cheat-sheet.
- `scripts/guard-kicad-write.sh` — `pgrep -i kicad` and `pgrep -fl kicad-mcp-pro` preflight. Exits non-zero if unsafe. Dry-run confirmed.
- AGENTS.md "Editing KiCad files outside KiCad" updated with pointer to the workflow doc.

**kicad-sch-api evaluation (`circuit-synth/kicad-sch-api` v0.5.6):**
- **Read works.** `load_schematic('kart-medulla_P1.kicad_sch')` → 105 components, 141 wires, parses cleanly. Useful as a Python read API.
- **Write does NOT preserve format.** Round-trip test (`/tmp/kicad-sch-api-test/roundtrip.py`) produced large diff: drops `(thickness 0.1524)` from text effects, reorders properties, fills empty `Description ""` fields with library text, etc. Despite claims of "exact format preservation".
- **Reference validator is wrong.** Rejects KiCad-valid power-flag references containing `+` and `_` (`#FLG_+12V01`, `#FLG_+5V_USB01`, `#FLG_+3V3`) as "Invalid reference format". Need to call internal `_file_io_manager.save_schematic(sch._data, path)` to bypass — but the format-preservation issue is separate and worse.
- **Verdict: skip the library entirely.** Writes are broken (format reformat + buggy validator). Reads work, but reads are already covered by `kicad-mcp-pro` (`sch_get_symbols`, `sch_trace_net`, `sch_get_connectivity_graph`, `run_erc`, `export_netlist`) and `kicad-cli sch export netlist` — both already in our toolbox, neither has the MCP-write cache problem since we'd only call read tools. `kicad-sch-api` adds zero value to us. Edit-tool surgical regex remains the only direct-write path (preserves format exactly when changes are tiny). Re-evaluate when KiCad 11 ships schematic IPC.

**PCB side, when we get there:** use `kicad-python` (the official KiCad IPC API). Works with running KiCad GUI, no cache war. Enable in `KiCad → Settings… → Plugins → API server`. https://dev-docs.kicad.org/en/apis-and-binding/ipc-api/

---

## 2026-05-08 — Source-of-truth flip + design clarifications (manual/auto mux, connector audit)

This session resolved several long-standing inconsistencies between the schematic, the pinout doc that lived in `~/dv/`, and what was actually built. Documenting the decisions here so we don't keep re-deriving them.

### Source of truth: dv-hardware (this repo) is canonical for chips and wiring

User's framing: "this is the pcb, can't be wrong." The schematic IS the physical artifact — derived docs can drift, the schematic cannot. So:

- `dv-hardware/projects/<board>/` is canonical for chip choices, nets, header pin assignments, decoupling, footprints. Anything that asks "what is on the board" → look at `kart-medulla.kicad_sch`.
- `~/dv/kart/<board>/` and `~/repos/kart-medulla` (firmware) defer. They carry firmware-specific overlays only: GPIO mode flags (open-drain etc.), idle-at-boot constraints, ISR notes, driver config.
- The pinout doc was moved from `~/dv/kart/kart-medulla/pinout-esp32-s3.md` to `dv-hardware/projects/kart-medulla/docs/pinout-esp32-s3.md`. The `~/dv/` copy is now a 7-line tombstone pointing here.
- Don't write "this repo is the source of truth" inside the source-of-truth repo itself — that's circular. The pointer goes in the deferring repo. (User caught me trying to do this in `dv-hardware/AGENTS.md`; reverted.)

**Why this matters going forward:** disagreements between the schematic and any doc → fix the doc, not the schematic. PCB layout is in progress, so pin assignments will keep shifting; the doc has a header note saying re-verify before each fab release.

### Brake mux dropped — one MAX4660 is enough

Original 2026-05-01 design had two MAX4660s muxing throttle and brake separately between manual and autonomous modes. User clarified 2026-05-08: brake doesn't need autonomous-vs-manual muxing because manual mode doesn't route brake through the ESP32 at all (the manual brake is mechanical/hydraulic, not electrical). So:

- U14 MAX4660 (throttle) — kept.
- U17 MAX4660 (brake) — was never placed on the schematic. Don't add it. The brake autonomous command (`CMD_BRAKE__0_10V` on CN5) goes directly from the MCP4922 (via the 0–5 V → 0–10 V op-amp gain stage) to the brake valve driver, no switch.
- `SELECT_THROTTLE` (ESP32 GPIO 15) drives U14 SELECT only. The "drives both MAX4660 SELECT pins" wording in the old doc is wrong and has been fixed.

### CMD_REVERSE moved off ESP32 GPIO onto PCF8574 P0 (decision was 2026-05-03, but the pinout doc was still claiming the old design)

Original 2026-05-02 plan: ESP32 GPIO 36 in `OUTPUT_OPEN_DRAIN` mode, wired in parallel with the manual reverse button (wired-OR through the motor controller's existing 5 V pull-up). 2026-05-03 it moved onto U25 PCF8574T port P0 (pin 4) instead. Reasons:

- Frees GPIO 36, which was the only N8R2-only-safe GPIO assignment we had — design is now fully N8R8-compatible (no signal depends on the quad-PSRAM-only GPIOs 33–37).
- PCF8574 quasi-bidirectional outputs are natively open-drain with weak internal pull-ups, so the wired-OR architecture works the same way without needing an `OUTPUT_OPEN_DRAIN` flag in firmware.
- Firmware change: `CMD_REVERSE` is now an I²C write to the PCF8574 output register (writing 0 pulls REVERSE_WIRE LOW, writing 1 releases it to high-Z). No special pin-mode config.

**Fail-safe property preserved:** ESP32 dead or I²C bus down → P0 stays in its power-on-default state (all outputs high = high-Z) → only the manual button controls the line. Identical behavior to manual-only operation.

### Schematic-vs-doc discrepancies on the ESP32 header (7 pins)

The pinout doc still said these pins were active when the schematic actually has NC markers. All fixed in `docs/pinout-esp32-s3.md`:

| Pin | GPIO | Doc said | Schematic shows | Reason it's NC |
|---|---|---|---|---|
| 3 | 19 | USB_D- (USB-OTG to Orin) | NC | No USB-C connector on the medulla PCB this rev |
| 4 | 20 | USB_D+ | NC | Same |
| 7 | 48 | LED (status RGB) | NC | Using the dev-module's onboard LED, not an external one |
| 20 | 44 | RX0 (UART0) | NC | Dev-board's onboard USB-UART bridge already owns GPIO 43/44 |
| 21 | 43 | TX0 (UART0) | NC | Same |
| 32 | 17 | TX1 (UART1) | NC / SPARE | UART1 unused — the only UART link off-board uses UART0 via dev-module USB-C |
| 33 | 18 | RX1 (UART1) | NC / SPARE | Same |

Lesson: when a pinout doc lives in a different repo from the schematic, it drifts. With the source-of-truth flip + the doc now next to the schematic, this should stay aligned.

### SELECT_THROTTLE wiring traced clean (no action needed, just for the record)

User asked to confirm `SELECT_THROTTLE` is correctly wired. It is:

- U23 (LEFT_HEADER, SSW-122-01-T-D dual-row) symbol pins 15 & 16 (paired = LEFT_HEADER row 8 = physical Pin 30 = silkscreen `15` = ESP32 GPIO 15) → wire (313.69, 63.5)–(370.84, 63.5) → label `SELECT_THROTTLE`.
- U14 MAX4660 pin 6 (IN, the SELECT input) at (405.13, 219.71) → wire (405.13, 219.71)–(410.21, 219.71) → label `SELECT_THROTTLE`.
- R32 = 10 kΩ at (410.21, 224.79) on the same node → matches the spec'd hardware-default-manual pulldown.
- Both labels are local on a single sheet, so they form one net by name. ERC: 0 violations.

Earlier `mcp__kicad__sch_trace_net` reported "labels=2 pins=0" — that's misleading; it doesn't count pins reached via wire+label, only direct pin-to-name matches. Don't use it as a "no pins on this net" indicator.

### External-connector audit (CN1–CN10) — captured in tasks.md

Crossed every signal on the 10× green push-in connectors (CN1–CN10) against the schematic netlist. One signal definitely missing from the connectors: **`SDC_ENABLE`** (GPIO 39 — meant to drive the external SDC enable relay). The schematic only has a free-text annotation "SDC_ENABLE — orphan, expected from external module" near U24 pin 14; no actual label, no wire, no connector exit. Action item logged in `.agents/tasks.md` under "External-connector audit".

Also flagged for verification (not necessarily wrong, just worth confirming before fab): CN4 has no GND for the AS5600 (3 pins: SDA/SCL/+3V3 only); `SDC_IN_LOW_SIDE` (CN5) vs `SDC_NOT_EMERGENCY__3V3` (internal) need to be confirmed as bridged via a divider; the manual-throttle passthrough relies on `PEDAL_ACC__0_5V` branching internally to both the ADC divider and U14 NC pin.

---

## 2026-05-08 — Open question: tasks.md is getting long for human peers, three options on the table

**Problem:** `.agents/tasks.md` was written agent-first per `AGENTS.md` ("shared kanban for agents to read and update"). Long-form rationale per task is good for AI continuity but bad for human peers skimming the file. User flagged this and asked for alternatives. No decision yet — leaving the file as-is until we pick.

**Options considered:**

1. **Folder-per-task (`.agents/tasks/<slug>.md`, with `tasks.md` as a one-line-per-task index).** Best fit if individual tasks start growing real discussion threads — each gets its own git history, can be assigned by filename prefix, and humans only see the index. Cost: a tiny bit of indirection for agents (extra file open per task).
2. **GitHub Issues for humans, lean `tasks.md` for agents.** If the team is already on GitHub, peers look at issues anyway. `tasks.md` becomes a short list of refs (`#42 — SDC_ENABLE wiring`). Cost: requires the project to be on GitHub with issues enabled, and adds a sync responsibility (close-issue ↔ move-to-Done).
3. **Just compress.** Keep one file, each entry becomes one short line ("SDC_ENABLE missing — wire GPIO 39 to a connector, see history.md 2026-05-08"). Rationale lives in `history.md` (which is what `history.md` was designed for). Cheapest to do, matches the existing "history.md as the explainer, tasks.md as the to-do" split.

**My recommendation if/when this is picked up:** option 3 first (one-pass cleanup, no structural change). Move to option 1 later if individual tasks start sprouting discussion. Option 2 only if the team is already living in GitHub Issues.

---

## 2026-05-08 — kart-medulla CN1–CN10 pin assignments locked to ESP32 geometry

User asked: with CN1–CN5 going up the right side of the PCB and CN6–CN10 going down the left side (mirroring the ESP32 module's "chip" pinout convention), what's the best signal-to-CN-pin assignment so jumper wires from each ESP32 pin to its CN pin stay short?

**Result — agreed assignment (CN pin 1 / 2 / 3):**

Right side (bottom→top):
- CN1: GND / +12V_IN / GND  — battery input
- CN2: MOTOR_HALL_3 (5V) / MOTOR_HALL_2 (5V) / +5V  — halls (2 of 3)
- CN3: CMD_STEER_DIR (3V3) / EXP_P1 / EXP_P2
- CN4: REVERSE_WIRE / SDC_IN_LOW_SIDE / CMD_STEER_PWM (3V3) — final, after two corrections during the session: (a) `SDC_NOT_EMERGENCY` removed from CN4.1 (it's an internal ESP32→Q3-gate net, must not be on a CN), and (b) the `MANUAL_THR`/`PEDAL_THR` placeholder I briefly proposed for the freed pin was wrong — the manual-throttle source is the same net as `PEDAL_ACC__0_5V` (CN6.1), branched internally to the MAX4660 NC pin; no second external pedal wire exists. CN4.1 ended up as `REVERSE_WIRE` (the genuinely missing external output that I had clobbered when renaming CN8.1).
- CN5: HYDRAULIC_2 (0–5V) / PRESSURE_3 (0–10V) / GND

Left side (top→bottom):
- CN6: PEDAL_ACC (0–5V) / PEDAL_BRAKE (0–5V) / +3V3
- CN7: PRESSURE_1 (0–10V) / PRESSURE_2 (0–10V) / MOTOR_HALL_1 (5V)
- CN8: SDA (I²C) / BUZZER / EXP_P3
- CN9: SCL (I²C) / HYDRAULIC_1 (0–5V) / EXP_P4
- CN10: CMD_ACC (DAC, 0–5V) / CMD_BRAKE (DAC, 0–5V) / GND

**Rejected: swap MH1 ↔ CMD_STEER_DIR on the ESP32 to cluster all three halls on one side.** Tempting because halls then live on CN2 alone, but GPIO 0 is a strap pin (must be HIGH at boot for normal boot mode). The hall level shifter U5 (SN74LVC3G17) is push-pull, so:
1. A pull-up to 3V3 on the MH1 net can't override U5 actively driving LOW at boot — if the rotor leaves the hall LOW at power-on, ESP32 enters ROM bootloader and the kart won't run until manually rolled and reset.
2. If firmware ever mis-configures the GPIO as output, two push-pull drivers fight, risking damage to U5 or the ESP32 pad.

Keeping CMD_STEER_DIR on GPIO 0 is safe because firmware actively drives it HIGH and the SDC keeps the Cytron disabled at boot regardless. So the swap stays NOT done; MH1 stays on GPIO 16 and rides on the left-side CN7 alongside the pressure sensors. Cable layout is fine because wires terminate in independent Wago slots — per-CN cable grouping doesn't have to match standard sensor pinouts.

**Aside on GPIO 45 / Pin 8:** user spotted "VSPI" on a third-party pinout image and asked if the pin is reclaimable. The label is misleading — on ESP32-S3 it's the **VDD_SPI voltage select strap** (not the classic ESP32 "VSPI" peripheral). Internal pulldown at boot selects 3.3V flash (correct for our N8R2). The pin is usable as a regular GPIO after boot, provided nothing externally pulls it HIGH at boot. Same rule applies to GPIO 46 (Pin 36). Both still listed as RESERVED in `pinout-esp32-s3.md` out of caution; can be promoted to SPARE-usable if a future need arises. Not needed for this assignment.

---

## 2026-05-08 — Stacked-symbol confusion: Reference field vs parent symbol in KiCad GUI

While cleaning up a stray `U02` reference, the user found the symbol via Cmd+F (with hidden-fields search) but couldn't select-and-delete it. Two compounding causes:

1. **Two GND symbols stacked at exactly the same coordinate** `(125.73, 311.15)` — a legacy `kart-medulla:GND` (rotated 270°, with the bogus `Reference: U02`) buried under a standard `power:GND` (rotated 90°). Clicking the GND triangle selects only the top one. Grep for the coordinate (`grep "at <x> <y>" *.kicad_sch`) reveals stacks instantly.
2. **Cmd+F selects the matched property/field, not the parent symbol.** When the match is on a hidden Reference field, the side Properties panel shows `Field` with `Text = U02` and a `Visible` checkbox — that's the reference text, not the symbol. Pressing Delete from there would (try to) delete a reference field, not the symbol. The user's intuition "I thought it was part of the symbol" is right — references *are* parts of symbols — but in the GUI they're a separately-selectable child of the symbol, and selecting the field doesn't promote selection to the parent.

**How to actually delete a buried symbol via its hidden field in KiCad 10:**
- Trick that worked: in the Properties panel, tick **Visible** on the field. The reference text now shows on the canvas, anchored to the parent symbol's origin. You can see *where* the symbol lives (even if its body is overlapped by another symbol's body). Then click the symbol body at that location and Tab-cycle through stacked items, or just delete the now-visible reference's parent.
- Alternative when GUI fights you: close KiCad, surgically delete the symbol block from the .kicad_sch (Mode B per `kicad-workflow.md`).

**Confirmed safe-to-delete signal for stacked GNDs:** if `grep "at <x> <y>"` shows two power symbols + a junction at the same point, deleting one is a no-op for connectivity — the remaining symbol + junction keep the net intact. Verify with `kicad-cli sch erc` after deletion (no new violations at that coordinate).

In this case the deletion landed cleanly on disk: U02 gone, coord-occurrence count at (125.73, 311.15) dropped 9 → 4 (one full symbol's worth of property positions removed), ERC has 0 new violations at that point.

---

## 2026-05-08 (later) — CN cluster reshuffle: U25 moved to right side, all PCF8574-related signals re-clustered

User decided to physically place U25 (PCF8574 GPIO expander) on the right side of the PCB near CN3, and asked to cluster all U25-related signals (I²C bus + expander outputs + reverse) on the right-side CNs to minimize routing length. Six labels swapped (none of the wire/footprint geometry changed; only the net names on the CN-side labels):

  - CN3.1: `CMD_STEER_DIR__3V3` → `EXP_P3`
  - CN4.2: `SDC_IN_LOW_SIDE` → `SDA__I2C`
  - CN4.3: `CMD_STEER__PWM_3V3` → `SCL__I2C`
  - CN8.1: `SDA__I2C` → `SDC_IN_LOW_SIDE`
  - CN8.3: `EXP_P3` → `CMD_STEER_DIR__3V3`
  - CN9.1: `SCL__I2C` → `CMD_STEER__PWM_3V3`

After: CN3 = pure EXP cluster (P1/P2/P3); CN4 = REVERSE_WIRE + SDA + SCL (all U25-facing); displaced ESP32 signals (CMD_STEER_DIR, SDC_IN_LOW_SIDE, CMD_STEER_PWM) land on left-side CNs (CN8/CN9) — their ESP32 GPIOs span both sides of the module, so route length is similar; the AS5600 I²C cable now exits through CN4 closest to U25.

Pre-existing naming inconsistency surfaced during this work: `CMD_STEER__PWM_3V3` uses double-underscore between `STEER` and `PWM` (parses as signal=`CMD_STEER`, level=`PWM_3V3`) while the matching `CMD_STEER_DIR__3V3` uses single underscore between signal-internal words and double before voltage. Should arguably be `CMD_STEER_PWM__3V3`. Not fixed in this pass to avoid net-rename churn before fab; tracked as a future cleanup.

---

## 2026-05-09 — EasyEDA footprint name "9N" includes exposed pad (false alarm on U14)

While auditing 3D-model coverage on kart-medulla, flagged U14 (MAX4660EUA+T) as having a "wrong" footprint: schematic and chip suggest 10 pins (μMAX-10), but EasyEDA-cached footprint `kart-medulla:SOP65P490X110-9N` has 9 pads. Initially diagnosed as a real footprint bug.

**It wasn't.** The footprint is 8 SMD leads + 1 exposed thermal pad (EPAD) underneath. EasyEDA's naming convention treats the EP as a numbered pad — hence "9N" = 8 leads + 1 EP, **not** 9 leads. The schematic agrees: pins 1–8 are real leads (with pin 5 marked NC), pin 9 is `EP` tied to GND. The 3D model rendering "only 8 pins" is correct because that's exactly what the chip looks like; the 9th pad is invisible from above.

**Lesson:** before claiming an EasyEDA footprint name like `<package>-<N>N` is wrong, count the SMD perimeter pads vs the body-center pad. Bottom EPAD doesn't appear in the chip's pin count but does appear in the footprint's pad count — almost universally for thermal-pad packages (DPAK, QFN, μMAX-EP, SOIC-EP). Don't assume `Nn` in the footprint name = chip pin count.

**Time cost:** ~10 minutes of misdirected investigation + a script run trying to re-attach a model that was already attached. Cheap, but worth not repeating on the next thermal-pad part.

---

## 2026-05-09 — Bulk-injecting 3D models into EasyEDA-imported footprints (kart-medulla)

**Trigger:** kart-medulla PCB had 58 of 59 footprints with no 3D model attached because the EasyEDA import doesn't ship `(model ...)` clauses for cached footprints. 3D viewer was nearly empty.

**Approach that worked:** scripted regex injection of `(model "${KICAD10_3DMODEL_DIR}/<lib>.3dshapes/<name>.step" (offset/scale/rotate ...))` blocks into each `(footprint ...)` block in `kart-medulla.kicad_pcb`, keyed on footprint name. **44 of 58 succeeded** on first pass (R0603, C0603, SOIC-8/14/16W, MSOP-8, SOT-23, TO-220-3, TO-252, PinSocket 1×22 + 2×22). Parens balanced afterward — no syntax damage.

**KiCad 10 env-var name:** `${KICAD10_3DMODEL_DIR}` (verified by grepping a stock `Resistor_SMD.pretty/R_0603_1608Metric.kicad_mod`). Earlier KiCad versions used `KICAD9_3DMODEL_DIR`, `KICAD8_3DMODEL_DIR`, etc. — the version number tracks the major release. Default base path on macOS: `/Applications/KiCad/KiCad.app/Contents/SharedSupport/3dmodels/`.

**Phoenix PTSA series not bundled.** KiCad ships `Connector_Phoenix_MC*`, `MSTB`, `GMSTB`, `SPT` 3dshapes — but **not** PTSA. For the 10× CN1–CN10 (`1990012`, PTSA 0,5/3-2,5-Z), downloaded STEP from SnapMagic (snapeda.com/parts/1990012/) and dropped at `projects/kart-medulla/3dmodels/1990012_PTSA_3p_2.5mm.step`. Referenced via `${KIPRJMOD}/3dmodels/...` so the project stays portable.

**Surprising finding — KiCad rotation sign convention differs between dialog and file.** The Footprint Properties → 3D Models dialog displays rotation values with **opposite sign** from what's stored in the .kicad_pcb. Verified empirically:
- File `(rotate (xyz -90 0 0))` → dialog shows `(90, 0, 0)`.
- Setting file to `(xyz 90 0 0)` (matching what dialog showed) flipped all 10 connectors upside down. Reverting to `(xyz -90 0 0)` restored correct upright orientation.
- Same pattern on Z: dialog `(0, 0, -90)` ↔ file `(xyz 0 0 90)`.
- Offsets and scale do **not** sign-flip — those are direct.

**Implication:** when a user reports values from the GUI, negate the rotation entries before writing to the file (or vice versa when reading the file to discuss with the user). Document both forms in any reference table.

**Failed iterations (good to remember so we don't redo them):**
- Asked user to nudge in Footprint Editor — wrong tool. Footprint Editor edits the *library* footprint, not the per-instance model offset. Per-instance offset only lives in pcbnew → click footprint → press `E` (Properties) → 3D Models tab. From the 3D Viewer (Alt+3) you can't edit anything; double-click does nothing.
- Tried inferring connector offset by guessing world-space displacement direction (`-1.41, 1.41, 0` then flipped X to `+1.41, 1.13, 0`). Both wrong, because the model offset is in the model's own (post-rotation, pre-yaw) frame and we don't know SnapEDA's authoring origin a priori. **Lesson: always ask the user to nudge ONE instance in the GUI and report exact numbers — then batch the rest. Don't guess offsets through coordinate-frame algebra; SnapEDA STEPs have arbitrary internal origins.**

**Final empirically-tuned values (verified visually in 3D viewer 2026-05-09):**

| Component | Footprint | 3D model | File rotation | File offset (mm) |
|---|---|---|---|---|
| CN1–CN10 (Phoenix PTSA 3p, 1990012) | `kart-medulla:CONN-TH_3P-P2.50-S5.00_1990012` | `${KIPRJMOD}/3dmodels/1990012_PTSA_3p_2.5mm.step` | `(xyz -90 0 0)` | `(-0.75, -1.2, 0)` |
| Q3 (IRLZ44N TO-220) | `kart-medulla:TO-220-3_L10.0-W4.5-P2.54-T` | `Package_TO_SOT_THT/TO-220-3_Vertical.step` | `(xyz 0 0 90)` | `(0, 2.54, 0)` |
| U24 (1×22 socket) | `kart-medulla:HDR-TH_ESQ-122-23-G-S` | `Connector_PinSocket_2.54mm/PinSocket_1x22_P2.54mm_Vertical.step` | `(xyz 0 0 90)` | `(26.6, 0, 0)` |
| U23 (2×22 socket) | `kart-medulla:HDR-TH_ESQ-122-59-G-D` | `Connector_PinSocket_2.54mm/PinSocket_2x22_P2.54mm_Vertical.step` | `(xyz 0 0 90)` | `(26.6, -1.5, 0)` |

Also re-recorded in `tasks.md` "3D-model placement values" section so peers' PCB edits don't silently regress them.

**Footprint name = body dimensions, not pin pitch alone.** EasyEDA's footprint names encode body L×W (e.g. `SOIC-8_L5.0-W4.0-P1.27-LS6.0-BL`), which doesn't always match KiCad's stock body (`SOIC-8_3.9x4.9mm_P1.27mm`). The 3D model still looks right because pin pitch matches; the body's a few tenths of a mm off but visually fine. Don't waste time hunting for an exact-body-size match unless the visual error is obvious.

**Phoenix Contact 1990012 logged to vault inventory:** `~/vault/inventory/phoenix-contact-1990012-ptsa-0_5-3-2_5-z-3pin-25mm-push-in-terminal-block.md`. Status `Noted`, `units_to_buy: 10`, source Mouser.

---

## 2026-05-09 — U19 (L7805) PCB-vs-AI-Inventory cross-check

PCB U19 uses footprint `kart-medulla:TO-252-2_L6.6-W6.1-P4.57-LS9.9-BR-CW`, value `L7805CDT_C20611927` (LCSC C20611927) — DPAK / TO-252-2, ST.

Notion AI Inventory (data_source `34a78747-3143-81da-85fb-000b14e5f8d8`) holds three rows for `L7805CDT-TR` (ST, Mouser 511-L7805CDT-TR), qty 10 + 5 + 15 = 30 in the Milwaukee components box. PCB part **matches** stock. Also one row of `LM7805CT/NOPB` (TI, qty 3) — TO-220 through-hole, **not** a footprint substitute.

Two cleanups worth doing in Notion (not yet done):
- All four 7805 rows have an empty `Package` field — should be `TO-252-2` for the STs and `TO-220` for the TI.
- The three ST rows look like schema-merge duplicates (same MPN, same Mouser PN, same location); consider consolidating into one row with qty 30.

---

## 2026-05-09 — AISLER sponsor logo placeholder size decision

Decided on the **smallest AISLER-spec size: 30 × 7.5 mm** (4:1 ratio, AISLER's stated minimum). Rationale: the only constraint that mattered was the 22.86 mm gap between the 0.9″ ESP32 headers, but the long axis goes parallel to the headers, not across the gap, so it wasn't actually binding. The biggest size we could have used (60 × 15 mm) and any intermediate (40×10, 50×12.5) would have fit too — went small because it looks better on this board.

Source for the 30 × 7.5 mm number: Rubén in #Driverless on 2026-05-06 ("la idea es que pongáis el recuadro de 30 × 7,5 mm donde os de la gana en la pcb") + the linked AISLER community thread (https://community.aisler.net/t/adding-our-logo-to-your-pcb/5382).

Drawing rules (from the AISLER doc, quoted verbatim where it matters): rectangle must be drawn as **4 individual lines** (the rectangle tool fails AISLER's auto-detect because it groups), line width **0.08382 mm (3.3 mil) exactly**, on silkscreen. AISLER doc says "Place as many placeholders as you want — each will be replaced with the logo," so placing one on F.Silkscreen *and* one on B.Silkscreen is allowed (default plan: do both).

---

## 2026-05-09 — Silkscreen text font: DejaVu Sans Mono (chosen by peer)

Peer working on the PCB layout used **DejaVu Sans Mono** for the CN1–CN10 silkscreen pin-label blocks. Tab-aligned columns rendered acceptably (not perfect — peer's words). Note for future cross-OS work: DejaVu Sans Mono ships by default on Ubuntu but **is not installed on macOS** (verified `fc-list` on Rubén's Mac 2026-05-09 — only Menlo, no DejaVu). There is no monospace font shared by default between macOS and Ubuntu. Options to keep the project cross-platform:

- Install DejaVu on Mac: `brew install --cask font-dejavu` (matches what the peer has).
- Use KiCad's **Embed Fonts** option (`File → Board Setup → Embedded Files` in KiCad 9+) — bakes the .ttf into the .kicad_pcb so the font travels with the project, regardless of who opens it.

Recommend turning on Embed Fonts before fab so the gerber export is deterministic across both machines.

---

## 2026-05-09 — AISLER Beautiful Boards DRC config + Power net class

Configured Board Setup constraints + a custom `kart-medulla.kicad_dru` file targeting **AISLER's "Beautiful Boards" 2-layer service** (the team's PCB-fab sponsor) with ~30 % margin over published minimums. Full rationale per number in `projects/kart-medulla/docs/drc-aisler.md`.

Headline numbers: track 0.20 mm, clearance 0.20 mm, drill 0.30 mm, via 0.55 mm Ø with 0.30 mm hole, copper-to-edge 0.30 mm, hole-to-hole 0.30 mm, silk 1.0 mm × 0.15 mm, silk-clearance 0.15 mm, microvias / blind-buried disabled.

**Net classes:** `Default` (track 0.25, clearance 0.20, via 0.6/0.3) and `Power` (track 0.50, clearance 0.25, via 0.8/0.4). Pattern-based assignment of `+12V`, `+5V_USB`, `+5V_REG`, `+3V3` to the Power class via `net_settings.netclass_patterns` in `.kicad_pro`. **`GND` deliberately stays in Default** — it's a poured zone, not a routed track, so a 0.5 mm minimum-track-width rule would be noise. **`3V3` is borderline** (low-current rail, ~200 mA peak); kept in Power for visual consistency, demote to Default if routing gets tight.

**Custom DRC rules** (`kart-medulla.kicad_dru`): `edge-clearance` (0.30 mm belt-and-suspenders), `annular-min` (0.125 mm extended to pads, not just vias), `hv-pressure-clearance` (0.60 mm on the three 24 V Festo pressure-sensor input nets — IEC 60664-1 Pollution Degree 2 / Material Group IIIa says 0.50 mm at 50 V working voltage; we're at 24 V outdoors so 0.6 mm gives derating + dust margin), `power-track-width` (0.50 mm Power-class backstop), `silk-pad-clearance`.

**Implementation gotcha (worth remembering):** edited `.kicad_pro` JSON behind a running KiCad — KiCad re-saved on close and silently clobbered the edits, reverting `min_clearance`, `min_track_width`, and the entire Power class. Lesson: **never edit `.kicad_pro` from outside while KiCad has the project open.** Either close KiCad first, or do all changes through Board Setup → Net Classes (which writes the schema KiCad expects, not whatever JSON shape an external tool guessed at).

**Net pattern syntax:** KiCad 10 patterns match against the **bare net name with leading `+`** (e.g. `+5V_USB`, `+3V3`, `+12V`) — **no leading slash**. The "Nets matching" preview pane in the Netclass Assignments dialog is the fastest way to confirm the pattern actually hits anything; an empty match means the pattern is wrong. Initially tried `/3V3`, `/+5V`, etc. — none matched (the medulla's actual nets are `+3V3`, `+5V_USB`, `+5V_REG`, `+12V`, with no bare `+5V`).

---

## 2026-05-09 — 3D-model regression after peer merge → surgical recovery → library-level fix

**Sequence of events** (all on 2026-05-09):

1. Earlier session bulk-injected 3D model `(model …)` blocks into 58 footprint instances in `kart-medulla.kicad_pcb` (recorded at "Bulk-injecting 3D models into EasyEDA-imported footprints" entry below). Bindings lived per-instance only — not in the `kart-medulla.pretty/` library.
2. Peer pushed two PCB-routing commits (`6b4914e`, `5f4ee9c`). When integrating, ran `git checkout origin/main -- kart-medulla.kicad_pcb` to take peer's layout. **This silently dropped 54 of 55 instance-level 3D bindings** — peer's local PCB had been re-imported / replaced at some point and didn't carry the per-instance `(model …)` blocks. Only `MAX4660EUA_T.step` survived because that one was already library-bound in `SOP65P490X110-9N.kicad_mod`.
3. Diagnosed via `grep '(model' kart-medulla.kicad_pcb | sort -u`: 1 ref where there had been 13. 3D viewer empty for everything except the MAX4660.
4. **Recovery:** found `kart-medulla.kicad_pcb.bak.20260509f` (KiCad auto-save from earlier in the session, pre-regression) with 55 intact bindings. Wrote a Python S-expression-walker that built `refdes → (model …) block` map from the .bak, then walked the current `.kicad_pcb` and injected the matching block into each footprint that lacked one. Layout/routing/silk untouched. 54 footprints restored, 4 unmatched (`PAD1–PAD4` corner mounting holes — correctly skipped). Committed as `9596513`.
5. Peer pushed *another* PCB commit (`5f4ee9c "logo and connections"`). Same regression: 3D bindings down to 1 again. Re-ran the surgical merge — same script, same `.bak` source — recovered all 55 again. Pushed atop peer's tip.
6. **Long-term fix:** edited 12 footprints in `kart-medulla.pretty/` to carry library-level `(model …)` blocks matching the format of the existing `SOP65P490X110-9N.kicad_mod`. Path / offset / scale / rotate values lifted verbatim from the `.kicad_pcb` (PTSA's `xyz -90 0 0` rotation + `-0.75 -1.2 0` offset preserved; ESQ-122 headers' `xyz -0 -0 90`; TO-220's `xyz 0 0 90`). Committed as `a0f7a5c`.

**Lessons / rules established:**

- **Per-instance 3D bindings are fragile.** Any operation that swaps the `.kicad_pcb` (re-import from EasyEDA, library footprint replace, `git checkout` from a peer branch lacking them) silently strips them. **Always bind 3D models at the `*.kicad_mod` library level** for parts intended to live on this board.
- **Instance-level still wins over library-level** in KiCad. Adding library bindings is non-destructive — if the live PCB already has a per-instance value, that wins. Used this property to land the library-level fix without coordinating around peer's in-flight layout work.
- **KiCad auto-saves saved us.** `kart-medulla.kicad_pcb.bak.20260509b/c/d/e/f` carried successive snapshots of the pre-regression state. Without them the surgery would have required re-deriving every per-instance offset/rotation by eye. **Don't gitignore the `.bak.*` files until after they've served their recovery purpose.** (Today the team's `.gitignore` was extended to `*.bak.*` — that's fine for the *future*, not for today's recovery, since the .bak files were already on disk.)
- **The Python S-expression walker** (parens-balanced footprint extraction + refdes-keyed model-block lookup) is reusable for any future "files diverged, want to merge specific subtrees" scenario in KiCad. Keep the snippet handy.

---

## 2026-05-09 — kart-medulla DRC cleanup session

- **Auto-silkscreen plugin installed:** CGrassin/kicad-auto-silkscreen at `~/Documents/KiCad/10.0/scripting/plugins/kicad-auto-silkscreen/`. Ran once to auto-place all refdes on medulla PCB. Side effect: ~50 silk-to-pad clearance warnings (largely cleaned up afterward).
- **Power-class minimum track width: 0.5 → 0.3 → removed.** Originally 0.5 mm in `71bf70d` (AISLER setup, sized for 1.5 A IPC-2152). Actual medulla Power loads (+12V, +5V_USB, +5V_REG, +3V3) are sub-100 mA — logic ICs, op-amps, sensors only. Cytron 12V→motor path does not traverse the medulla (per 2026-05-01 decision). Dropped to 0.3 mm, then removed entirely once QFN/SOT-23 fanout demanded 0.2 mm pitch on power rails. Power class still enforces clearance (0.25 mm) and via size (0.8/0.4 mm). Updated `kicad_dru`, `kicad_pro` (Power netclass `track_width: 0.5 → 0.2`), and `projects/kart-medulla/docs/drc-aisler.md`.
- **Bulk power-track widening broke 36 connections.** Edit Track & Via Properties → "Set to net class / custom rule values" with Power-class filter widened all power tracks at once; endpoints shifted off pads. Unconnected items 3 → 39. Manual repair brought it back to 4; some still broken at session end.
- **Polygon rule area for fine-pitch SMD pad clearance.** First attempt used custom DRC rule with `A.MemberOfFootprint == B.MemberOfFootprint` — invalid in KiCad 10, broke rules compilation entirely. Replaced with rule-area approach: drew polygon (`fine-pitch-smd`) around U14, added rule:
  ```
  (rule "fine-pitch-pad-clearance"
    (constraint clearance (min 0mm))
    (condition "A.insideArea('fine-pitch-smd') && B.insideArea('fine-pitch-smd') && (A.Type == 'Pad' || B.Type == 'Pad')"))
  ```
  Resolves 7 intra-footprint pad-pad / track-pad violations on U14 (SOIC-8, 0.65 mm pitch, native 0.18 mm pad-pad). Reusable pattern for future fine-pitch parts.
- **U14 solder-mask bridges fixed via `solder_mask_margin`.** Six "Rear solder mask aperture bridges items with different nets" errors. Cause: each pad in the U14 footprint had `solder_mask_margin 0.102`, expanding apertures by 0.102 mm/side and shrinking the mask web below AISLER minimum. Initial fix targeted wrong file (`SOP65P400X130-8N.kicad_mod`); U14 actually uses `SOP65P490X110-9N.kicad_mod` (8-µMAX-EP, 9 pads incl. exposed pad), confirmed by inspecting the embedded footprint in `.kicad_pcb` (sibling 8N footprint also exists in library, `parts.md` was ambiguous). Set `solder_mask_margin 0` on correct file. **Tools → Update Footprints from Library does NOT override per-pad mask margin** (treated as user customization) — required direct sed on the embedded copy in `.kicad_pcb` to push through.
- **Min thermal spoke count: 2 → 1** (Board Setup → Constraints, per-zone). Acceptable for hand-soldered prototype; vibration/thermal-cycling longevity not a concern. Per-zone setting — existing zones may not pick up the change automatically, may need editing individually.
- **U14 confirmed: MAX4660EUA+T**, 8-µMAX-EP, footprint `SOP65P490X110-9N` from SnapEDA. Not yet in `~/vault/inventory/` — worth adding (mirror `phoenix-contact-1990012-...` format).
- **Final DRC state:** 0 errors. 5 silk text warnings (U1 refdes 0.087 mm thickness / 0.69 mm height — below AISLER 0.10 mm hard floor; 3 TrueType texts with thin stroke). 4 unconnected items pending fix.

## Reference

- KiCad EasyEDA importer docs: https://dev-docs.kicad.org/en/import-formats/easyeda/index.html
- ConvertEDA (worked): https://converteda.com
- KiCad IPC API (for future automation): https://dev-docs.kicad.org/en/apis-and-binding/ipc-api/for-addon-developers/index.html
- `kicad-python` (official Python bindings for IPC API): https://pypi.org/project/kicad-python/

## 2026-05-12 — WAGO push-in terminal block sourcing (2624 vs 2601)

**Trigger:** Spotted WAGO 2624 series in an Instagram reel (wagouk), wanted a 3.5 mm pitch variant compatible with team standard 18 AWG / 0.75 mm² wire (`~/vault/standards.md:236-239`).

**Finding:** The **2624 series has no 3.5 mm pitch.** Only 5 mm (2624-11xx top entry, 2624-31xx side entry) and 7.5 mm (2624-15xx, 2624-33xx). The 3.5 mm pitch sibling with same push-in-CAGE-CLAMP + lever style is the **2601 series** (e.g. 2601-3104 = 4-pole, 3.5 mm pitch, top entry). Conductor range 0.2–1.5 mm² (AWG 26–14). Don't assume pitch options carry across WAGO series numbers — verify on wago.com before quoting.

**Pitch / current cheat-sheet for push-in cage-clamp lever PCB terminals:**

| Pitch | Series | Conductor range | Rated current | Use case |
|---|---|---|---|---|
| 3.5 mm | **2601** | 0.2–1.5 mm² (AWG 26–14) | ~10 A | Signal + low-power (CAN, I²C, 0.75 mm² standard wire) |
| 5 mm | **2624** | 0.2–1.5 mm² (AWG 24–12) | ~17 A | General purpose |
| 7.5 mm | **2624-3xxx** | 0.5–6 mm² (AWG 20–10) | ~41 A | Power (4 mm² / 12 AWG, 30 A loads) |

**Modularity (Arduino-header-like behavior):** at the same pitch, N×1-pole bodies abut to span the same hole pattern as one N-pole body. PCB footprint with 4 holes at 3.5 mm pitch accepts 1× 2601-3104 OR 2× 2601-3102. Body height/depth ≈13×17 mm — leave clearance.

**Datasheet retrieval:** WAGO's own product pages don't expose static PDF URLs (priintcloud signatures are dynamic, return HTTP 400 without a session). **Bürklin mirrors clean PDFs** at `https://www.buerklin.com/Buerklin-Webshop-Site/rest;loc=de_DE/attachments/Buerklin-Webshop%253A%252FFiles_<hash>%252F<PN>-EN.pdf` — grep the product page HTML (`/en/p/wago/pcb-terminal-blocks/<PN>/<bürklin-id>/`) for the file hash. Bürklin product IDs found via search: 2601-3102 → 09H828, 2601-3103 → 09H830, 2601-3104 → 09H832.

**Final sourcing decision — stock 2-pole + 3-pole only.** Per-pin pricing is flat across pole counts (DigiKey 1-off, 2026-05): 2601-3102 $1.21/pin, 2601-3103 $1.12/pin, 2601-3104 $1.13/pin. No per-pin saving from buying higher pole counts. With {2-pole, 3-pole} you can compose every integer pole count ≥ 2 with zero gaps (2 and 3 are coprime → Frobenius = 1). 4-pole adds nothing the 2+3 set can't.

**Inventory (Notion, all "To order", 10 units each):**
- 2601-3102 (2-pole): https://www.notion.so/WAGO-2601-3102-2-pole-PCB-terminal-block-3-5-mm-pitch-push-in-lever-35e7874731438115b893eacecfce7026
- 2601-3103 (3-pole): https://www.notion.so/WAGO-2601-3103-3-pole-PCB-terminal-block-3-5-mm-pitch-push-in-lever-35e787473143816c80bdf020e0de2d64
- 2601-3104 (4-pole): created then archived after the per-pin pricing check.

Datasheets at `~/dv/datasheets/2601-310{2,3}_wago_datasheet.pdf` (4-pole removed). Standards entry added at `~/vault/standards.md` under the connectors section.

## 2026-07-10 — kart-medulla ESP32 module identified on hardware: N16R8, not N8R2

Read the fitted dev board over its COM (USB-UART) port with `esptool 5.2.0`. Measured, not recalled:

| Property | Value |
|---|---|
| Chip | ESP32-S3, QFN56, revision v0.2 |
| Base MAC | `14:c1:9f:2a:a6:18` |
| Flash | 16 MB, external, quad line (`FLASH_TYPE` eFuse = 4 data lines; `FLASH_CAP` = none, i.e. no in-package flash) |
| PSRAM | 8 MB, AP Memory, 3.3 V (`PSRAM_CAP` = 8M, `PSRAM_VENDOR` = AP_3v3) |
| USB-UART bridge | WCH CH343/CH9102, VID `0x1A86` PID `0x55D3`, product string "USB Single Serial" |

**Module is an N16R8, not the N8R2 the docs claimed.** The supplier shipped the wrong
variant. 8 MB in-package PSRAM on the ESP32-S3 only exists on the R8 die, which uses an
**octal** interface — Espressif ships no 8 MB quad variant. So GPIO 33-37 are wired to the
PSRAM die and are unusable on this board.

**No signal has to move.** The 2026-05-03 decision to push `CMD_REVERSE` onto PCF8574 P0 and
the 2026-05-08 moves (BUZZER 36→3, MOTOR_HALL_1 37→16, CMD_STEER_DIR 35→0) already made the
pinout octal-safe. Verified: in the live S3 pin table GPIO 35/36/37 are `HOLD` and 33/34 are
unassigned. The variant-agnostic layout paid for itself. `pinout-esp32-s3.md` updated
(title, octal-PSRAM note, pin-10 row, "module variant in use").

**The board is a DevKitC-1-compatible clone, not an Espressif board.** Espressif's own
ESP32-S3-DevKitC-1 bridges UART through a CP2102N (VID `0x10C4`, Silicon Labs) and silkscreens
its ports `UART`/`USB`; this one uses a WCH bridge and silkscreens `COM`/`USB`. Functionally
equivalent for our purposes. It does have two USB-C ports, so checklist item 2 in
`pinout-esp32-s3.md` ("verify native USB reaches GPIO 19/20") can be settled without a
multimeter: plug a cable into the free `USB` port and see whether it enumerates as VID `0x303A`
(the S3's built-in USB-Serial-JTAG, which needs no firmware). **Not yet done.**

Open contradiction inside `pinout-esp32-s3.md`, noticed but not resolved: the status legend says
"USB_D+/- pins not wired on this PCB", while the dev-board checklist (item 2) describes GPIO
19/20 carrying USB D-/D+ to the Orin. Someone should reconcile these against the schematic.

## 2026-07-10 — kart-medulla bench bring-up: SDC MOSFET (Q3) verified working

Board on the bench, CN8 unplugged, nothing connected to the kart. Driven from the MicroPython
REPL over the `COM` (USB-UART) port.

**Q3 (IRLZ44N, SDC low-side switch) works.** Toggled `SDC_NOT_EMERGENCY__3V3` (GPIO 18) as a
2.5 Hz square wave and measured with a multimeter. Gate follows the GPIO; drain
(`SDC_IN_LOW_SIDE`, CN8 pin 1) alternates between open and ~0 Ω to GND in step with it.
Neither failure mode is present: not stuck open (dead FET) and — more importantly — not stuck
closed (drain-source short, which would assert "no emergency" permanently regardless of firmware).

**Fail-safe default confirmed.** With GPIO 18 left as a high-impedance input, the gate reads 0:
R23's 100 kΩ pulldown holds Q3 off, so the kart powers up in the *emergency* state before
firmware drives anything. This is the behaviour the SDC design depends on.

**The chip is running MicroPython v1.19.1 (2022-06-18, IDF v4.4.1), not our ESP-IDF firmware.**
Found by reading the partition table out of flash (`nvs` / `phy_init` / `factory` 0x10000+0x1f0000
/ `vfs` FAT at 0x200000 — MicroPython's standard ESP32 layout) and grepping the app image. Nobody
recorded this anywhere. Nothing was flashed or erased during this session. Note the ESP-IDF
firmware in `~/repos/kart-medulla` cannot currently build for the S3 at all — see that repo's
`.agents/error-log.md` (2026-07-10) for the GPIO 18 / steering-PWM collision that a naive port
would introduce.

**Serial reliability: use 115200 for anything long.** `esptool read-flash` of the 16 MB image
failed at 921600 ("Serial data stream stopped") and again at 460800 ("Invalid head of packet") at
only 1.5%. 115200 was flawless. This matches the warning already in the firmware repo's AGENTS.md,
which was written about a CP2102 but holds for the CH343 too.

**U25 (PCF8574) is populated and alive on I²C.** Scanned SDA=GPIO 8 / SCL=GPIO 9. One device at
`0x20`, stable across repeated scans, returning `0xFE` (P0 low, P1–P7 high). P0 is `CMD_REVERSE`.
No AS5600 at 0x36, expected since the steering encoder is off-board and unattached. Read-only
probing was used; nothing was written to the expander, so `CMD_REVERSE` was never asserted.

**The part not yet soldered is U5, the 5 V→3V3 level shifter for the motor hall sensors** (waiting
on Mouser). So `MOTOR_HALL_1/2/3` cannot be read until U5 is fitted. (Earlier in this session the
missing part was mis-recorded as U25; corrected by Rubén.)

## 2026-07-10 — kart-medulla CN connectors face inward; pin order runs against CN order

Rubén, handling the assembled board: the wire entry of all ten CNs points **inward** toward the
middle of the PCB, and the pins within each connector count *backwards* relative to the CN
sequence. Verified against `kart-medulla.kicad_pcb`: CN1–CN5 (right) sit at rotation −90° with
pin 1 at top while the CNs ascend bottom→top; CN6–CN10 (left) sit at +90° with pin 1 at bottom
while the CNs ascend top→bottom. Both sides are counter-directional.

Proposed fix: rotate every CN 180°, which makes wires exit outward *and* puts the pin numbering
in sequence with the CN numbering on both sides. Caveat: the footprint
`CONN-TH_3P-P2.50-S5.00_1990012` has staggered pads (pins 1+3 one row, pin 2 a row 5.00 mm
across), so the flip relocates pin 2's row and forces a re-route under every connector. Task
written up in `projects/kart-medulla/tasks.md`; `docs/pinout-cn-connectors.md` corrected — it had
claimed "pin 1/2/3 from top to bottom" for all ten, which is only true of CN1–CN5.

## 2026-07-16 — tasks.md consolidated to the repo root; `.agents/tasks.md` retired

**Trigger:** Rubén's call — "tasks.md are tasks no matter if I do them or you do them. They're the
tasks of the project, and mixing two tasks.md files can only create confusion and duplicate or
outdated files."

**Background:** the split came from a rule in global `~/.claude/CLAUDE.md` that reserved a repo's
root `tasks.md` for Rubén's personal to-do list and put the agent board in `.agents/tasks.md`. The
2026-05-12 entry above already recorded the tension (agent-first long-form rationale being bad for
human peers skimming the file) and closed with "no decision yet". This is that decision.

**Done:**
- `git mv .agents/tasks.md tasks.md` (history preserved; the 4 then-uncommitted lines were
  committed first so the move is revertible).
- `AGENTS.md` knowledge-files list now points at root `tasks.md` and states there is no
  `.agents/tasks.md`.
- `projects/kart-medulla/tasks.md` header now points cross-board work at `dv-hardware/tasks.md`.
- Global `~/.claude/CLAUDE.md`: the personal-vs-agent split is replaced with "one `tasks.md` per
  project, at the repo root"; `tasks.md` removed from the `.agents/` read-mode list.

**Not done, deliberately:** earlier `history.md` and `.agents/error-log.md` entries still say
`.agents/tasks.md`. Those are dated append-only records and were accurate when written — rewriting
them would falsify the log. This entry is the forwarding pointer.

**Scope that survives:** per-board lists stay at `projects/<board>/tasks.md`. That is scoping by
board, not a competing board — root `tasks.md` is cross-board only.

**Doc bug spotted while doing this:** `AGENTS.md` tells contributors "Newest entries first" for this
file, but the file is and always has been oldest-first (2026-05-03 at the top, newest appended at the
bottom), which is what global CLAUDE.md specifies. The instruction is wrong, not the file. Left as-is
pending Rubén's call on which way to fix it.

## 2026-07-16 — kart-medulla board list moved to `tasks/kart-medulla.md`; one tasks.md per repo, no exceptions

**Trigger:** Rubén tightened the rule the same day it was written: "just 1 tasks.md file at the root.
no exceptions. only possible tasks/ folder for more complex tasks, but still those are referenced
from tasks.md at the root."

The earlier entry today consolidated `.agents/tasks.md` into the root but kept
`projects/kart-medulla/tasks.md` as "per-board scoping". That was the same two-boards shape the
consolidation existed to kill — 199 lines in the board folder against 149 at the root — and it is now
closed. Contradiction 3 in `tasks.md` is resolved by this.

**Done:**
- `git mv projects/kart-medulla/tasks.md tasks/kart-medulla.md` (history preserved).
- Root `tasks.md` gained a "Task files" index. The rule is that the root board is the only index: a
  file under `tasks/` that isn't linked from it doesn't exist as far as anyone is concerned.
- `AGENTS.md`: layout now shows `tasks.md`, `tasks/<name>.md` and `projects/<board>/requirements.md`;
  the knowledge-files entry states one `tasks.md` per repo at the root, no `.agents/tasks.md` and no
  `projects/<board>/tasks.md`.
- References repointed in `projects/kart-medulla/requirements.md` and the root board.

**Left alone deliberately:** `.agents/tasks.md` and `projects/kart-medulla/tasks.md` mentions inside
earlier `history.md` and `.agents/error-log.md` entries. Dated append-only records, accurate when
written; rewriting them would falsify the log. This entry is the forwarding pointer.

## 2026-07-16 — PCB checklist extracted to `docs/pcb-checklist.md`; revisions get names

**Trigger:** Rubén, reading the board list: "i'm seeing lots of tasks in tasks.md which are actually
just the pcb checklist. we should create a finishable task like 'pass the pcb checklist (linking it)
for the new revision of the pcb' and make sure we call each pcb with a different name."

**The problem:** the checklist existed in **four** places, all diverging — "PCB checklist — pre-fab
review and validation" and "Tomorrow (2026-05-10): pre-fab finishing" and "PCB finishing pass
(pre-fab)" as task sections, plus a copy in the team Google Drive (`el/pcb-checklist.md`, last
touched 2024-12-04, heading still "formula 23-24"). Checklist items make bad tasks: they are never
"done", they recur every revision, and copying them is what produced the four copies.

**Done:**
- `docs/pcb-checklist.md` — one checklist for every board: Design, Pre-fab validation, Revision
  naming. Merged from all in-repo copies plus the Drive one. Includes the track-width rule that came
  out of the compressor-power-path discussion the same day: a net's copper is its job description.
- `tasks/kart-medulla.md` now carries **one** finishable task — "Pass the PCB checklist for
  `medulla-v2`" — linking the doc instead of restating it. Done = every box ticked, board tagged,
  fab package under `fab/kart-medulla/v2/`.
- The two pre-fab sections were moved off the root board (they were kart-medulla-specific, so they
  never belonged on a cross-board list) into the board's file, wrapped in a `<details>` and marked
  superseded rather than pruned — the "Tomorrow (2026-05-10)" section is two months stale and Rubén
  should decide what survives.
- Revision naming written down: `<board>-v<N>`, on the silkscreen, in the title block, on the git
  tag, and on the `fab/<board>/<rev>/` folder. Numbers are never reused.

**Assumption flagged, not resolved** (`tasks.md` contradictions 7–8): the v1/v2 mapping treats the
assembled EasyEDA-origin board as `medulla-v1`, following the "V2 Hardware Improvements" heading.
Nothing on disk confirms it — `fab/` is empty and the only tag is `medulla-v0.1-converted`.

## 2026-07-16 — root board reduced to cross-board work; kart-medulla items consolidated

Checking that the checklist task linked correctly exposed that the root `tasks.md` was still almost
entirely kart-medulla work — silkscreen legend, AISLER logo, 3D-model values, connector audit, the
"In Progress: PCB layout" and "Done: LM358" entries, and the whole "Notes for the next person"
section. The root/board split announced this morning was therefore fiction: the root board *was* the
old kart-medulla cleanup board under a new name, and the same board's work lived in two files —
exactly the shape the consolidation existed to remove.

**Done:** everything kart-medulla moved verbatim (statuses preserved) into `tasks/kart-medulla.md`
under a "Moved from the root board" heading. Root keeps only genuinely cross-board work — the WAGO
2601 terminal-block standard — plus the `tasks/` index and the open-contradictions list. The
redundant "Design the buzzer circuit" pointer stub was dropped; the real task with the inventory
parts and the FS-Rules SPL constraint is in the board file.

**Lesson:** renaming a file does not change what's in it. The morning's move made the root board
*named* cross-board while its contents stayed board-specific, and nothing caught that until a link
check forced a read of the actual sections.

## 2026-07-18 — Compressor gate drive: why 3.3 V is not enough, and what the HUABAN module gives us

The EBS compressor was bench-run for the first time today (firmware detail in the `kart-medulla`
repo, `history.md` 2026-07-18). It works, but it exposed a hardware problem that belongs to this
repo, and it changes what `medulla-v2` has to carry. Task written up in
[`tasks/kart-medulla.md`](tasks/kart-medulla.md).

### The concern: a 3.3 V gate cannot drive a power MOSFET properly

The compressor is switched by an **IRLZ44N** with its gate wired straight to a 3.3 V ESP32 pin.
Measured: **6 A running at 60% duty**, and the MOSFET reached **~100 C even after the duty was cut to
20%** — hot enough on the first run at 60% to bake the adhesive around the part (the die survived).

The cause is arithmetic, not bad luck. The IRLZ44N datasheet specifies Rds(on) at Vgs = 10 V
(0.022 Ohm), 5 V (0.025) and 4 V (0.035), **and stops there**. 3.3 V is below the last specified
point, with Vgs(th) max = 2.0 V, so the device never fully enhances — roughly 0.05-0.07 Ohm cold and
~1.6x that hot. Against Rth(j-a) = 62 C/W in a bare TO-220 that is over 100 C of rise. Conduction
loss dominates switching loss by roughly 50x at 500 Hz, so **PWM frequency cannot fix it** and
neither can lowering the duty much further (the 60% -> 20% step gave far less than expected, because
motor current does not fall with duty when the pump is working against tank pressure).

Two findings worth carrying into any future board:

1. **"Logic level" on a datasheet front page means it works at 5 V, not 3.3 V.** A survey of ~150
   datasheets across Infineon, Vishay, Nexperia, Toshiba, ST, onsemi, Diodes and AOS found the
   industry floor for a *specified* Rds(on) is **Vgs = 4.5 V**. Vgs(th) max on power dice runs
   2.0-2.5 V, so a worst-case part is at threshold with a 2.5 V gate and no vendor guarantees
   anything below. Only two parts qualified at all and both had a catch (IRF3708, TO-220, specified
   at 2.8 V but obsolete; CSD17307Q5A, in production but SON surface-mount). **Assume 3.3 V direct
   gate drive is never acceptable for a power MOSFET, and budget a driver.**
2. **Beware the plot-label false positive.** Nearly every one of those datasheets contains the
   strings "VGS = 2.5 V" and "VGS = 3 V" — as *curve labels on the Rds(on)-vs-Vgs graph*, never as
   table rows. A parametric search hit claiming a 2.5 V spec is usually reading a plot annotation.
3. **The pin does not even deliver a clean 3.3 V.** The ESP32-S3 datasheet specifies IOH = 28 mA
   only at VOH >= 0.8 x VDD = **2.64 V**, so during the Miller plateau — exactly when the die is
   dissipating — the pin sags toward 2.64 V.

### What the HUABAN module gives us

In inventory: **HUABAN 4 x 25A MOSFET HA210N06 3D Printer Heated Bed Power Extension Module**,
Amazon ASIN `B089YD5XP6`, rated **25 A**, board **60 x 50 mm**, M3 mounting holes, currently listed
as unavailable. It carries an HA210N06 in TO-3P with a clip-on finned heatsink (~3 x 2 x 1 cm),
a 2-pin JST "Control In", and screw terminals marked "HOT BED" and "+ DC IN -". Datasheet for the
transistor is filed at `kart-medulla/datasheets/HA210N06_datasheet.pdf`.

It is useful to this repo in two ways:

- **As a parts donor.** The MOSFET plus heatsink can be moved onto the medulla board. But the
  HA210N06 is **not** a logic-level part — Vgs(th) is 2/3/4 V min/typ/max and Rds(on) is specified at
  exactly one point, Vgs = 10 V. Harvested on its own and wired to a 3.3 V GPIO it would be *worse*
  than the IRLZ44N fitted today, which at least specifies down to 4.0 V. Its gate is also large
  (Qg = 135 nC, Ciss = 5800 pF, about 3x the IRLZ44N), so even ignoring voltage an ESP32 pin at
  ~20 mA needs ~7 us to move the charge. **If the transistor is harvested, the driver must be
  designed in alongside it.**
- **As a reference design.** The carrier has a `U2` stage with a small resistor network that appears
  to level-shift the control input up to the DC-IN rail. If so, that is exactly the circuit v2 needs,
  already proven at 25 A, and worth copying rather than inventing.

### Open question, to test next session

**Does the module's control input actually accept 3.3 V?** Believed yes, but by *inference only*:
3.3 V is below the HA210N06's worst-case 4 V threshold, so a pass-through carrier could not work with
the 3.3 V printer boards these modules are sold for — therefore it almost certainly boosts the gate.
The Amazon listing gives no control-voltage specification, and `U2` has not been identified.

**The measurement that settles it:** 12 V on DC IN, 3.3 V on Control In, then read **gate-to-source**
at the MOSFET pads. Three outcomes, not two:
- **~10-12 V** — a level-shift stage is present and reaches the rail. The module is usable as-is and
  its `U2` circuit is worth copying onto v2.
- **~5 V** — a stage exists but only reaches a 5 V rail. Still inadequate: that is 1 V of overdrive
  against a 4 V worst-case threshold, with Rds(on) unspecified there.
- **~3.3 V** — pass-through, no stage at all, and no MOSFET choice helps without adding a driver.

(Terminology: "level shifter", not "boost". Nothing steps the voltage up — the small transistor
simply switches the big gate between GND and the 12 V rail that is already present on DC IN. A
single-transistor version of this inverts, so a non-inverting module needs two stages or a driver
IC, which is why `U2` being a SOIC-8 rather than a SOT-23 is a useful clue.)

*(Recorded because it was stated with more confidence than it deserved during the session: the
earlier advice "do not drive it from 5 V" was about the MOSFET **gate**, whereas the module's
**control input** is a different node. Both statements are compatible, but only the first is
verified.)*

## 2026-07-30 — The brake / proportional-valve command leaves the board at 0–5 V; the 0–10 V amplifier output goes nowhere

Triggered by a review of the net names around `CMD_BRAKE` on the `kart-medulla` PCB. The intended
signal chain is: MCP4922 DAC generates 0–5 V → LM358 amplifies ×2 to 0–10 V → out through a push-in
terminal to the Festo proportional pressure regulator. Only the first two thirds of that chain exist
on the board.

**Method.** Parsed `projects/kart-medulla/kart-medulla.kicad_pcb` directly (KiCad was open, so this
was read-only; no MCP writes, no file edits). Note for future parsing: in KiCad 10 board files a pad
carries `(net "NAME")` with **no net number** — a regex expecting `(net <n> "NAME")` silently matches
nothing and looks like "the net does not exist".

### Verified net map (as built)

| Net | Every pad on it |
|---|---|
| `/P1/CMD_ACC_ESP32__0_5V` | U13.14 (MCP4922 VOUTA), U14.8 (MAX4660 NO) |
| `/P1/CMD_ACC__0_5V` | U14.1 (MAX4660 COM), CN10.1 |
| `/P1/PEDAL_ACC__0_5V` | U14.2 (MAX4660 NC), CN6.2, R14.2 |
| `/P1/CMD_BRAKE__0_5V` | U13.10 (MCP4922 VOUTB), U1.3 (LM358 +IN1), **CN10.2** |
| `Net-(U1A--IN1)` | U1.2 (LM358 −IN1), R19.1, R20.2 |
| `/P1/CMD_BRAKE__0_10V` | U1.1 (LM358 OUT1), R19.2 — **and nothing else** |

The amplifier itself is correct: R20 = 1 kΩ from −IN1 to GND, R19 = 1 kΩ from −IN1 to OUT1, so
gain = 1 + R19/R20 = 2, and 0–5 V in gives 0–10 V out. U1 is supplied +12 V on pin 8 and GND on
pin 4. The unused half U1B is tied off as a follower (pin 7 → pin 6, pin 5 → GND).

### Issue 1 — the connector pin is on the wrong side of the amplifier

`CN10.2` sits on `CMD_BRAKE__0_5V`, i.e. **directly on the DAC output**, in parallel with the
amplifier input. `CMD_BRAKE__0_10V` terminates at the op-amp output and its own feedback resistor
and never reaches a connector, so the amplified signal cannot leave the PCB. The board therefore
sends 0–5 V to a device that expects 0–10 V — full DAC scale commands roughly half the pressure
range, and no code change can recover the other half.

This did not show up in ERC or DRC because `CMD_BRAKE__0_10V` has two pads on it. A net with two
connections is electrically legal; nothing checks that one of them is an exit point.

### Issue 2 — the DAC output pin is exposed on an external terminal with no protection

Because `CN10.2` is the DAC node, whatever the harness presents at that terminal lands directly on
MCP4922 VOUTB (and on the LM358 input). There is no series resistor, no clamp, no buffer. The
destination device runs on a 24 V supply, so a wiring fault or a pull-up on the receiving side puts
24 V onto a 5 V-supplied analog output pin. (The MCP4922's exact absolute-maximum rating on VOUT has
not been read — its datasheet is not yet filed in the board's `datasheets/` folder — but no 5 V CMOS
DAC output survives 24 V.) Moving the connector to the amplifier
output (Issue 1) also fixes this, since the op-amp output tolerates a short far better than the DAC
does. This risk is **not** an ESP32 risk — `CMD_BRAKE__0_5V` does not touch the ESP32 sockets U23/U24
at any pad; the ESP32 only reaches the DAC over SPI (see below).
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

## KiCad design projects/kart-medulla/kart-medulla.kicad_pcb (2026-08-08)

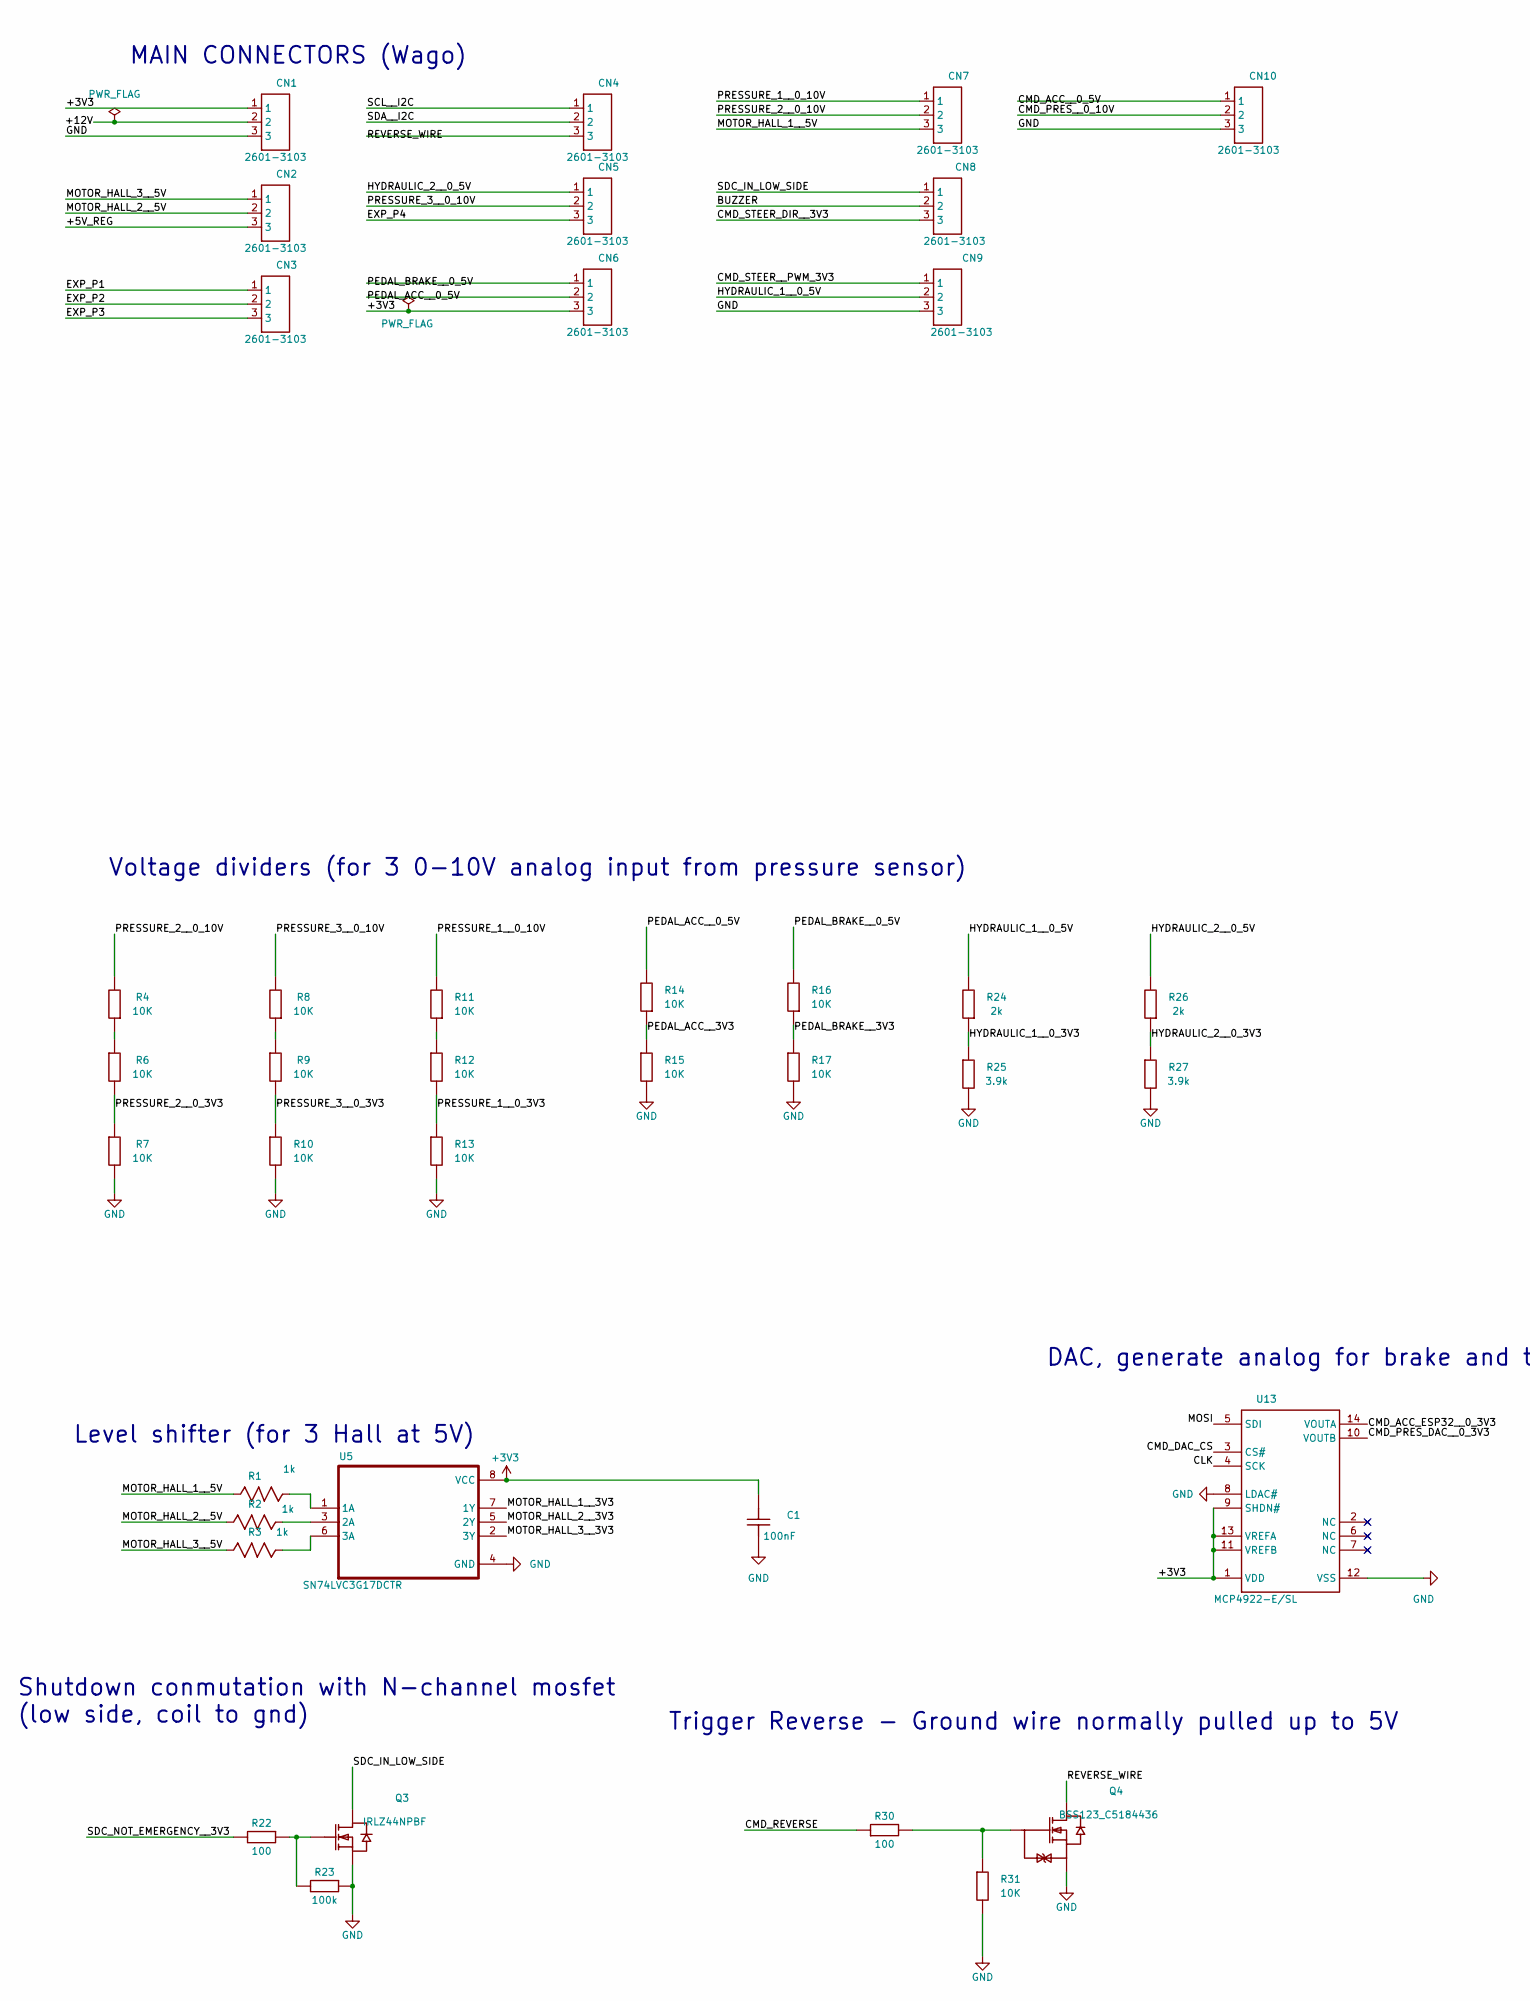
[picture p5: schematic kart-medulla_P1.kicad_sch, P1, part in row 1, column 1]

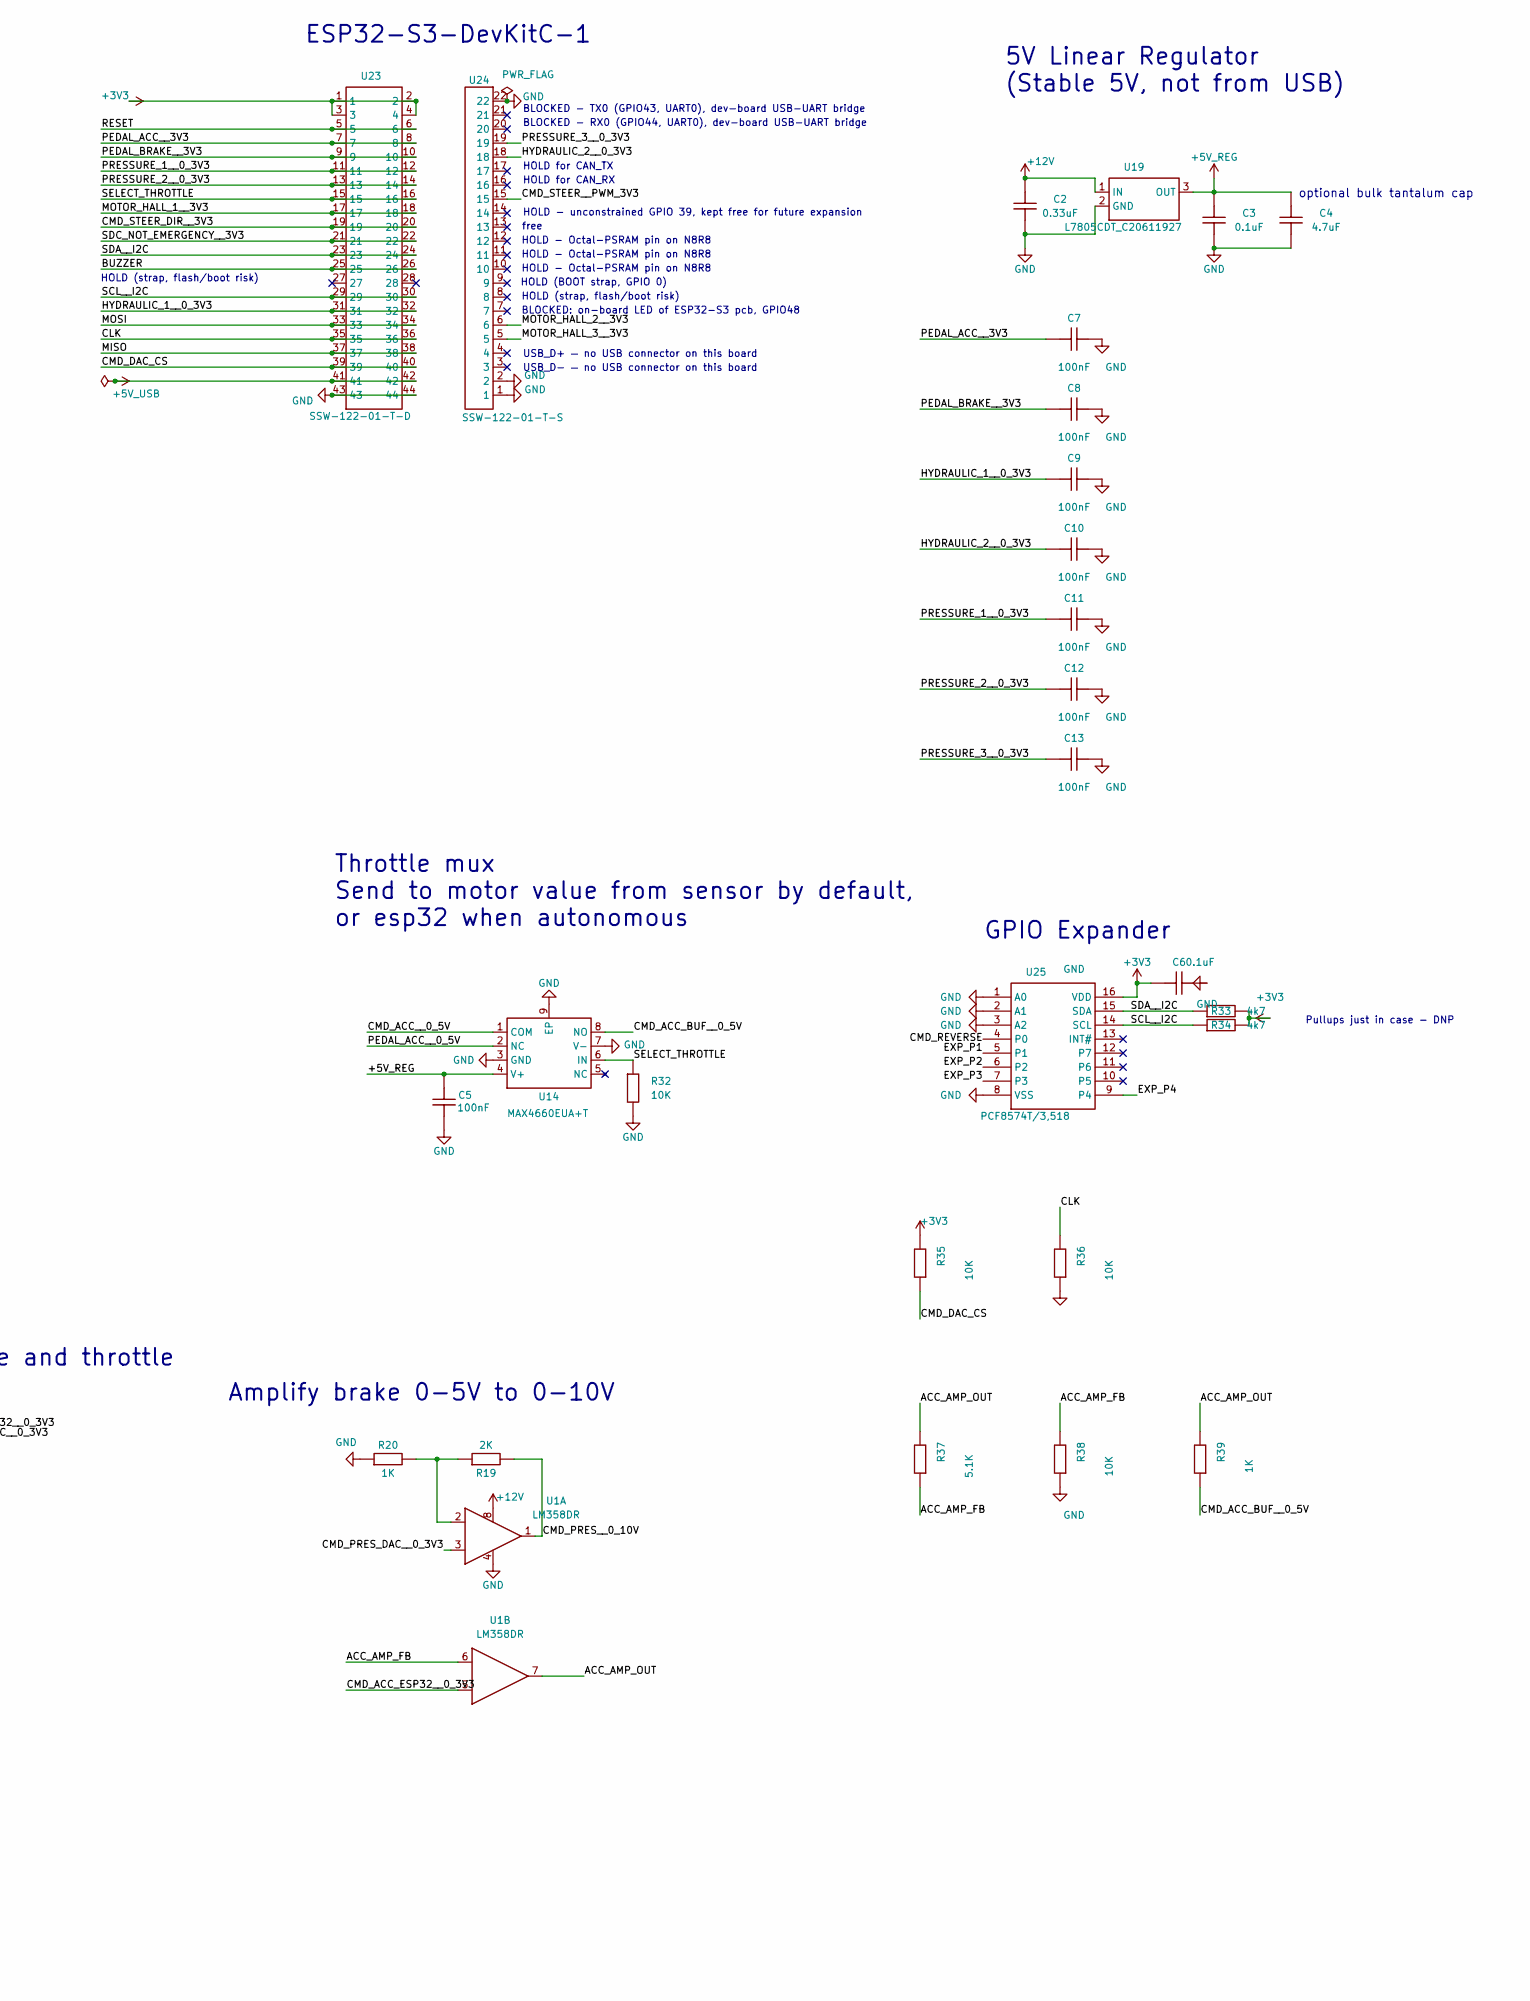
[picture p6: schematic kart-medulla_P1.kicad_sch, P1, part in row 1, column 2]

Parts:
C1: 100nF; C0603; part_bbox -10.5,-8.5,10.5,8.5
C2: 0.33uF; C0603; part_bbox -10,8,10,-8
C3, C6: 0.1uF; C0603; part_bbox -10,8,10,-8
C4: 4.7uF; C0603; part_bbox -10,8,10,-8
C5: 100nF; C0603; part_bbox -10,8,10,-8
C7, C8, C9, C10, C11, C12, C13: 100nF; C0603
CN1, CN2, CN3, CN4, CN5, CN6, CN7, CN8, CN9, CN10: 2601-3103; TerminalBlock_WAGO_2601-3103_1x03_P3.50mm_Vertical; part_bbox -10,-20,10,20
Q3: IRLZ44NPBF; TO-220-3_L10.0-W4.5-P2.54-T; part_bbox -10.5,-10.5,24.5,10.5
Q4: BSS123_C5184436; SOT-23_L2.9-W1.3-P1.90-LS2.4-BR; part_bbox -22.5,-13.5,23.5,20.5
R1, R2, R3: 1k; R0603; part_bbox -15.5,-5.5,15.5,5.5
R4, R6, R7, R8, R9, R10, R11, R12, R13, R14, R15, R16, R17, R31, R32: 10K; R0603; part_bbox -10,4,10,-4
R19: 2K; R0603; part_bbox -10,4,10,-4
R20: 1K; R0603; part_bbox -10,4,10,-4
R22, R30: 100; R0603; part_bbox -10,4,10,-4
R23: 100k; R0603; part_bbox -10,4,10,-4
R24, R26: 2k; R0603; part_bbox -10,4,10,-4
R25, R27: 3.9k; R0603; part_bbox -10,4,10,-4
R33, R34: 4k7; R0603; part_bbox -10,4,10,-4
R35, R36, R38: 10K; R0603
R37: 5.1K; R0603
R39: 1K; R0603
U1: LM358DR; SOIC-8_L5.0-W4.0-P1.27-LS6.0-BL; part_bbox -21,-22.69999999999999,21,21
U5: SN74LVC3G17DCTR; SOP65P400X130-8N; part_bbox -50,40,50,-40
U13: MCP4922-E/SL; SOIC-14_L8.7-W3.9-P1.27-LS6.0-BL; Manufacturer Part MCP4922-E/SL; JLCPCB Part Class Extended Part
U14: MAX4660EUA+T; SOP65P490X110-9N; part_bbox -25,-25,35,25
U19: L7805CDT_C20611927; TO-252-2_L6.6-W6.1-P4.57-LS9.9-BR-CW; part_bbox -20,-20,30,10
U23: SSW-122-01-T-D; HDR-TH_ESQ-122-59-G-D; part_bbox -20,-110,20,120
U24: SSW-122-01-T-S; HDR-TH_ESQ-122-23-G-S; part_bbox -10,-115,10,115
U25: PCF8574T/3,518; SOIC-16_3.9x9.9mm_P1.27mm; part_bbox -30,-45,30,45

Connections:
+3V3: C1.1, C6.2, CN1.1, CN6.3, R33.2, R34.2, R35.2, U5.8 (VCC), U13.1 (VDD), U13.9 (SHDN#), U13.11 (VREFB), U13.13 (VREFA), U23.1, U23.2, U23.3, U23.4, U25.16 (VDD)
+5V_REG: C3.2, C4.2, C5.2, CN2.3, U14.4 (V+), U19.3 (OUT)
+5V_USB: U23.41, U23.42
+12V: C2.2, CN1.2, U1.8 (+V), U19.1 (IN)
/P1/ACC_AMP_FB: R37.1, R38.2, U1.6 (-IN2)
/P1/ACC_AMP_OUT: R37.2, R39.2, U1.7 (OUT2)
/P1/BUZZER: CN8.2, U23.25, U23.26
/P1/CLK: R36.2, U13.4 (SCK), U23.35, U23.36
/P1/CMD_ACC_BUF__0_5V: R39.1, U14.8 (NO)
/P1/CMD_ACC_ESP32__0_3V3: U1.5 (+IN2), U13.14 (VOUTA)
/P1/CMD_ACC__0_5V: CN10.1, U14.1 (COM)
/P1/CMD_DAC_CS: R35.1, U13.3 (CS#), U23.39, U23.40
/P1/CMD_PRES_DAC__0_3V3: U1.3 (+IN1), U13.10 (VOUTB)
/P1/CMD_PRES__0_10V: CN10.2, R19.2, U1.1 (OUT1)
/P1/CMD_REVERSE: R30.1, U25.4 (P0)
/P1/CMD_STEER_DIR__3V3: CN8.3, U23.19, U23.20
/P1/CMD_STEER__PWM_3V3: CN9.1, U24.15
/P1/EXP_P1: CN3.1, U25.5 (P1)
/P1/EXP_P2: CN3.2, U25.6 (P2)
/P1/EXP_P3: CN3.3, U25.7 (P3)
/P1/EXP_P4: CN5.3, U25.9 (P4)
/P1/HYDRAULIC_1__0_3V3: C9.2, R24.1, R25.1, U23.31, U23.32
/P1/HYDRAULIC_1__0_5V: CN9.2, R24.2
/P1/HYDRAULIC_2__0_3V3: C10.2, R26.1, R27.1, U24.18
/P1/HYDRAULIC_2__0_5V: CN5.1, R26.2
/P1/MISO: U23.37, U23.38
/P1/MOSI: U13.5 (SDI), U23.33, U23.34
/P1/MOTOR_HALL_1__3V3: U5.7 (1Y), U23.17, U23.18
/P1/MOTOR_HALL_1__5V: CN7.3, R1.1
/P1/MOTOR_HALL_2__3V3: U5.5 (2Y), U24.6
/P1/MOTOR_HALL_2__5V: CN2.2, R2.1
/P1/MOTOR_HALL_3__3V3: U5.2 (3Y), U24.5
/P1/MOTOR_HALL_3__5V: CN2.1, R3.1
/P1/PEDAL_ACC__0_5V: CN6.2, R14.2, U14.2 (NC)
/P1/PEDAL_ACC__3V3: C7.2, R14.1, R15.1, U23.7, U23.8
/P1/PEDAL_BRAKE__0_5V: CN6.1, R16.2
/P1/PEDAL_BRAKE__3V3: C8.2, R16.1, R17.1, U23.9, U23.10
/P1/PRESSURE_1__0_3V3: C11.2, R12.2, R13.1, U23.11, U23.12
/P1/PRESSURE_1__0_10V: CN7.1, R11.2
/P1/PRESSURE_2__0_3V3: C12.2, R6.2, R7.1, U23.13, U23.14
/P1/PRESSURE_2__0_10V: CN7.2, R4.2
/P1/PRESSURE_3__0_3V3: C13.2, R9.2, R10.1, U24.19
/P1/PRESSURE_3__0_10V: CN5.2, R8.2
/P1/RESET: U23.5, U23.6
/P1/REVERSE_WIRE: CN4.3, Q4.3 (D)
/P1/SCL__I2C: CN4.1, R34.1, U23.29, U23.30, U25.14 (SCL)
/P1/SDA__I2C: CN4.2, R33.1, U23.23, U23.24, U25.15 (SDA)
/P1/SDC_IN_LOW_SIDE: CN8.1, Q3.2 (D)
/P1/SDC_NOT_EMERGENCY__3V3: R22.2, U23.21, U23.22
/P1/SELECT_THROTTLE: R32.1, U14.6 (IN), U23.15, U23.16
GND: C1.2, C2.1, C3.1, C4.1, C5.1, C6.1, C7.1, C8.1, C9.1, C10.1, C11.1, C12.1, C13.1, CN1.3, CN9.3, CN10.3, Q3.3 (S), Q4.2 (S), R7.2, R10.2, R13.2, R15.2, R17.2, R20.1, R23.1, R25.2, R27.2, R31.2, R32.2, R36.1, R38.1, U1.4 (GND), U5.4 (GND), U13.8 (LDAC#), U13.12 (VSS), U14.3 (GND), U14.7 (V-), U14.9 (EP), U19.2 (GND), U23.43, U23.44, U24.1, U24.2, U24.22, U25.1 (A0), U25.2 (A1), U25.3 (A2), U25.8 (VSS)
unnamed: Q3.1 (G), R22.1, R23.2
unnamed: Q4.1 (G), R30.2, R31.1
unnamed: R4.1, R6.1
unnamed: R8.1, R9.1
unnamed: R11.1, R12.1
unnamed: R19.1, R20.2, U1.2 (-IN1)
unnamed: R1.2, U5.1 (1A)
unnamed: R2.2, U5.3 (2A)
unnamed: R3.2, U5.6 (3A)

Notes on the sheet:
Pullups just in case - DNP
GPIO Expander
Level shifter (for 3 Hall at 5V)
Trigger Reverse - Ground wire normally pulled up to 5V
optional bulk tantalum cap
ESP32-S3-DevKitC-1
HOLD for CAN_TX
Shutdown conmutation with N-channel mosfet (low side, coil to gnd)
USB_D- — no USB connector on this board
HOLD - Octal-PSRAM pin on N8R8
DAC, generate analog for brake and throttle
Amplify brake 0-5V to 0-10V
HOLD for CAN_RX
HOLD (strap, flash/boot risk)
MAIN CONNECTORS (Wago)
HOLD (BOOT strap, GPIO 0)
BLOCKED - TX0 (GPIO43, UART0), dev-board USB-UART bridge
BLOCKED - RX0 (GPIO44, UART0), dev-board USB-UART bridge
BLOCKED: on-board LED of ESP32-S3 pcb, GPIO48
free
Voltage dividers (for 3 0-10V analog input from pressure sensor)
USB_D+ — no USB connector on this board
HOLD - unconstrained GPIO 39, kept free for future expansion
Throttle mux Send to motor value from sensor by default, or esp32 when autonomous
5V Linear Regulator (Stable 5V, not from USB)

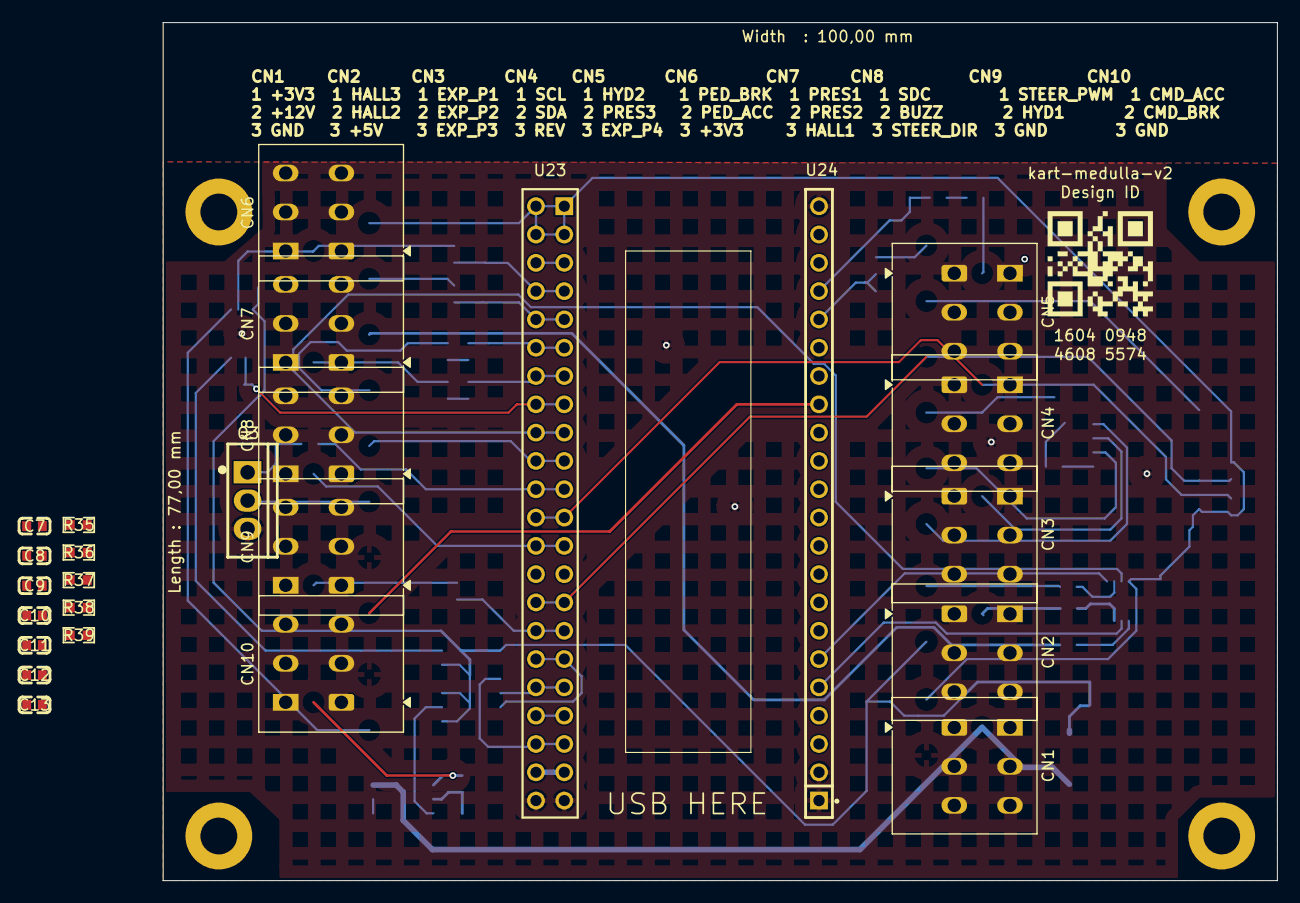
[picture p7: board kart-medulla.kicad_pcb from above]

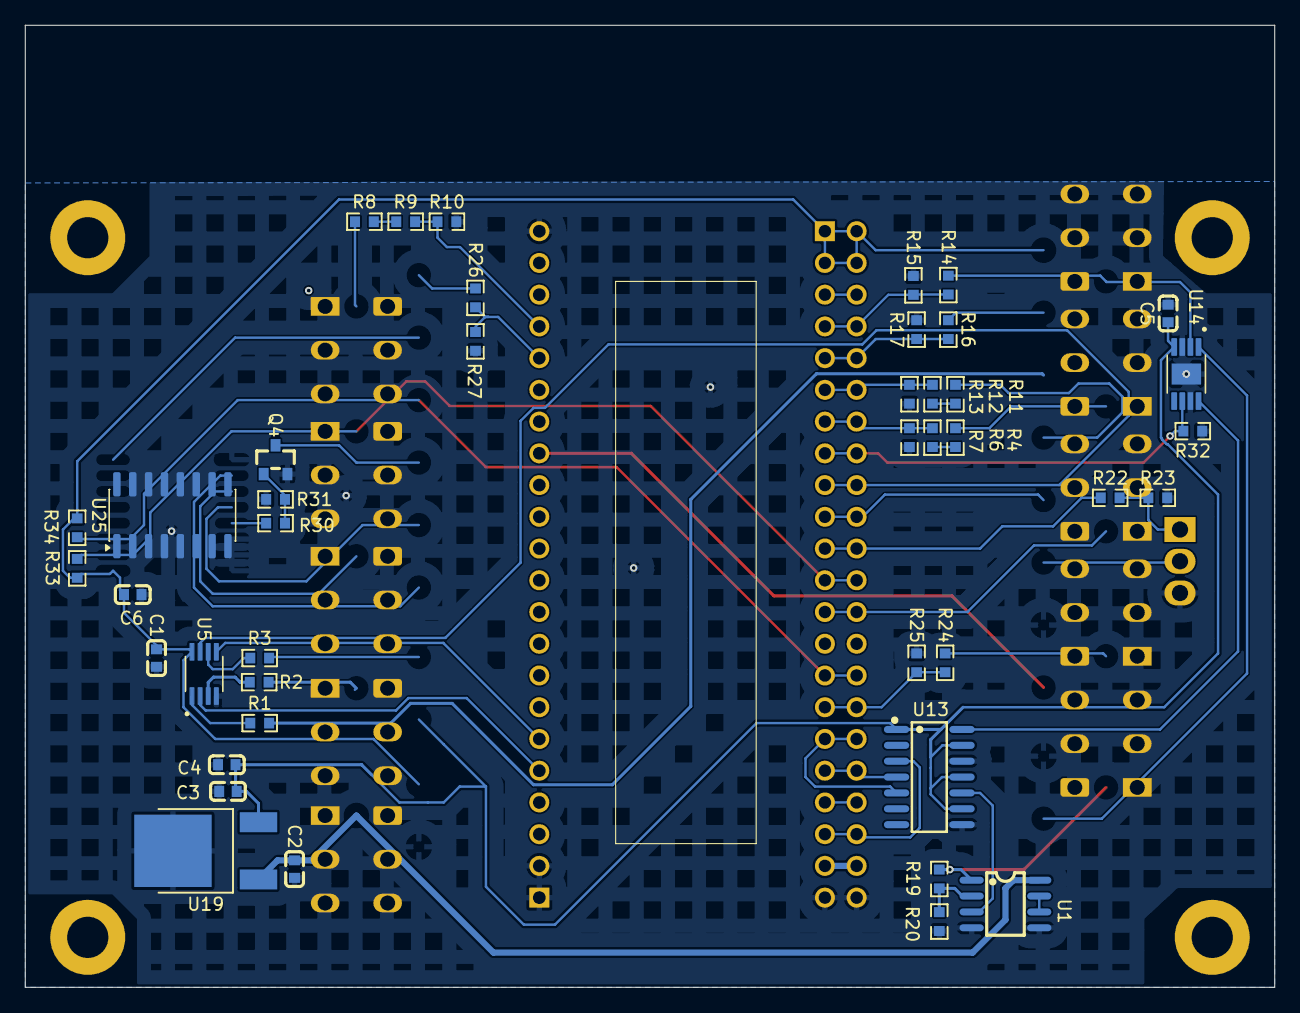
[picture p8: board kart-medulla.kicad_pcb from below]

Board: 2 copper layers, 100.0 x 77.0 mm, 71 parts (42 on the bottom side), 60 nets.

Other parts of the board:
PAD1: single_pad; standalone_pad_0001
PAD2: single_pad; standalone_pad_0002
PAD3: single_pad; standalone_pad_0003
PAD4: single_pad; standalone_pad_0004

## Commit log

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2026-05-03 kart-medulla: import via ConvertEDA (raw baseline)
    KiCad 10.0.1's native EasyEDA Pro importer silently failed on this
    project (.epro from EasyEDA Pro 2.2.47.7 produced empty stubs).
    Used https://converteda.com instead — clean output: 175KB PCB,
    251KB schematic, 36 footprints in project-local .pretty/.
    Renamed all internal refs from 'Kart_Medulla_(expander_for_ESP_32)'
    to 'kart-medulla' (filenames, sheet refs, project name in instances,
    title block).
    Validation:
    - kicad-cli sch erc: 347 violations (lib refs to absent 'gen' lib,
    'power' lib mismatches like 12V/+5V_REG, missing fp-lib-table)
    - kicad-cli pcb drc: 165 violations + 31 unconnected
    All expected post-conversion cleanup, not con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
    [kart-medulla.kicad_pcb, kart-medulla.kicad_sch, kart-medulla_P1.kicad_sch]
2026-05-03 drop accidental files from easyeda-source/
    Two things slipped into the previous commit:
    - .history/ as a submodule pointer (KiCad's local-history dir has
    its own internal .git, which made git treat it as a submodule
    and bypass the .history/ gitignore rule).
    - Empty .kicad_pcb/.kicad_sch/.kicad_pro stubs (79/230/2 bytes)
    that KiCad created when opening the .epro before we did the
    proper ConvertEDA-based import.
    Tightened gitignore to also exclude any KiCad files inside
    easyeda-source/ — that dir is the source archive only.
    [kart-medulla.kicad_pcb, kart-medulla.kicad_sch]
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2026-05-03 kart-medulla: add wire+label stubs to empty connector pins
    Added 8 wire+label pairs to:
    CN8 pins 1,2 (pin 3 already had REVERSE_WIRE)
    CN9 pins 1,2,3
    CN10 pins 1,2,3
    Wires are 36.83 mm horizontal stubs extending leftward, matching
    the CN4-CN7 pattern. Endpoints land on the schematic grid so they
    attach cleanly to the connector pins.
    Labels are placeholders named <REF>_<PIN>_TODO. Rename each in
    eeschema once you decide which signal goes where (e.g. EXP_P0,
    RELAY_1_EN). Grep for TODO to find any forgotten ones; ERC will
    also surface them as single-endpoint nets until matching labels
    appear at the U25 (PCF8574T) end.
    - File still parses (re-ran kicad-cli sch erc)
    - All 8 wi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
    [kart-medulla.kicad_sch, kart-medulla_P1.kicad_sch]
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2026-05-03 kart-medulla: cleanup U25 stub conflicts + add labels; log lessons
    Conflicts found and removed (initial replication pass missed
    non-wire connection markers on these pins):
    - U25 pin 5 (P1): hierarchical_label CMD_REVERSE was already
    placed directly on the pin attach point (no wire). Removed
    my redundant stub wire.
    - U25 pin 12 (P7): no_connect marker on the pin (intentionally
    unused). Removed my conflicting stub wire.
    Labels added at endpoints of legitimate stubs:
    - U25 pin 4 (P0): EXP_P0_TODO
    - U25 pin 13 (INT#): EXP_INT_TODO (user-added stub)
    ERC: 377 -> 373 (-4: removed 2 conflicting wires + their warnings;
    added 2 single-endpoint label warnings, net -2; minus 2 mo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
    [kart-medulla_P1.kicad_sch]
2026-05-03 kart-medulla: fix mislabeled GPIO stubs + add P2-P6 stubs
    Two bugs found and fixed:
    1. Y-flip bug: KiCad lib_symbols use Y-up; instantiated symbols
    use Y-down. Initial PCF8574T pin coord calc forgot the flip,
    so pin numbering was inverted vertically. Result: my prior
    'EXP_P0_TODO' label was sitting on actual pin 5 (P1), and
    'EXP_INT_TODO' was on actual pin 12 (P7). Renamed in place:
    EXP_P0_TODO -> EXP_P1_TODO (it's on P1, was always)
    EXP_INT_TODO -> EXP_P7_TODO (it's on P7, was always)
    2. With pin coords corrected, audited remaining empty GPIO pins.
    Added 21.59mm stubs + TODO labels on the 5 truly-empty ones:
    P2 (pin 6): EXP_P2_TODO (leftward stub)
    P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
    [kart-medulla_P1.kicad_sch]
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2026-05-03 kart-medulla: upgrade CN10 GND from plain label to power symbol
    CN10 pin 3 GND is now a proper #PWR36 power symbol (lib_id
    power:GND, rotation 270 so the triangle points away from the
    connector wire) — matches the visual style of every other GND
    on the schematic.
    Two-step fix needed in the symbol block: update the (property
    'Reference' '#PWR36') AND the (instances ... (reference '#PWR36'))
    sub-block. KiCad uses the instances-path reference for display,
    not the property field — missing that update made ERC report
    the new symbol as #PWR08 (the template's number) for one round.
    ERC: 366 -> 367 (+1 lib_symbol_mismatch — same cosmetic warning
    every other GND in the schematic produces; the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
    [kart-medulla_P1.kicad_sch]
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2026-05-03 kart-medulla: register footprint library + prefix all schematic Footprint props
    User registered the project-local kart-medulla.pretty/ library via
    KiCad's Manage Footprint Libraries dialog (creates fp-lib-table).
    But ERC kept complaining because every schematic symbol's
    (property 'Footprint' '...') had a bare footprint name like
    'CONN-TH_3P-...' with no library prefix — KiCad parsed that as
    library='' (empty) and then complained the empty-string library
    isn't registered.
    Fix: prepend 'kart-medulla:' to all 55 non-empty Footprint
    properties. ConvertEDA dropped the lib prefix during import.
    ERC: 367 -> 313 (-54: every footprint_link_issues warning gone).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
    [kart-medulla.kicad_pcb, kart-medulla_P1.kicad_sch]
2026-05-04 kart-medulla: rename power flags to KiCad stdlib names (3V3 -> +3V3, 12V -> +12V)
    Renamed both the cached lib_symbol entries and all instance lib_id
    references for the two power symbols whose names didn't match KiCad's
    standard 'power' library naming convention:
    power:3V3 -> power:+3V3
    power:12V -> power:+12V
    (the +5V_REG and +5V_USB symbols are intentionally custom-named to
    distinguish regulator domains, kept as-is.)
    Surprising side effect: kicad-cli sch erc reports 0 violations now
    (was 313). All categories cleared, including the 55 'gen library
    missing' warnings, the 62 unconnected_wire_endpoint, the 25
    lib_symbol_mismatch, etc. Plausible explanation: KiCad's ERC
    silently bails on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
    [kart-medulla_P1.kicad_sch]
2026-05-04 kart-medulla: fix nested unit-symbol names for renamed power flags
    When the parent (symbol 'power:12V') was renamed to 'power:+12V'
    in the previous commit, the nested child sub-symbols inside the
    cached lib_symbol definition kept their old names:
    '12V_0_1', '12V_1_1', '3V3_0_1', '3V3_1_1'
    KiCad's parser builds child unit names as <ParentName>_<unit>_<body>
    and rejects mismatched prefixes — failing schematic load entirely
    ('Invalid symbol unit name prefix 12V_0_1'). The eeschema GUI
    caught this with a clear error dialog; kicad-cli sch erc silently
    bailed and reported '0 violations' (a CLI bug worth knowing).
    Renamed the 4 child symbols to match the parent: +12V_0_1,
    +12V_1_1, +3V3_0_1, +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
    [kart-medulla_P1.kicad_sch]
2026-05-04 kart-medulla: extract cached symbols to project lib + register sym-lib-table
    Resolves all lib_symbol_issues (66) and lib_symbol_mismatch (25) ERC warnings
    by giving every lib_id a real on-disk library backing. The 21 cached symbols
    (gen:* and power:*) were extracted into projects/kart-medulla/kart-medulla.kicad_sym
    and lib_ids rewritten to nickname kart-medulla:*. ERC: 313 -> 222.
    [kart-medulla_P1.kicad_sch]
2026-05-04 kart-medulla: convert hierarchical_label -> global_label (flat design)
    The schematic is a single sheet, so hierarchical_label fires
    hier_label_mismatch errors with no parent sheet pin to match. Converting
    all 8 instances to global_label resolves the 5 errors. CMD_REVERSE now
    collides with a local label of the same name (new same_local_global_label
    warning) - to clean up next. ERC: 222 -> 218.
    [kart-medulla_P1.kicad_sch]
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2026-05-04 kart-medulla: rename power flags to +3V3/+12V; convert U24 text→labels
    Two changes:
    1. Power flag rename to KiCad stdlib convention: 3V3 → +3V3, 12V → +12V
    (consistent with +5V_REG/+5V_USB which already had +). Touches both
    the project lib and the cached lib_symbols block + all instances.
    2. The right-side annotations on U24 ('GND', 'TX0', 'RX0', 'USB_D+/-',
    'LED', 'STRAP_PIN_8', 'SDC_NOT_EMERGENCY__3V3') were plain (text)
    elements — visually labels, but electrically nothing. Replaced with
    real (global_label) at the wire endpoints, snapped to (427.99, y).
    ERC: 83 → 70. pin_not_connected on U24: 10 → 0. The remaining
    isolated_pin_label warnings on TX0/RX0/USB_D+/-/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
    [kart-medulla_P1.kicad_sch]
2026-05-04 kart-medulla: convert remaining U23 left-side text→global_labels + fix GND collision
    5 more pseudo-labels were plain (text) on the left side of U23
    (RESET, TX1, RX1, MISO, GND), each sitting at a wire endpoint but
    not electrically connected. Converted to global_label.
    Renamed the U24 pin-14 label from SDC_NOT_EMERGENCY__3V3 to
    SDC_ENABLE (the actual signal name from the user's original text;
    SDC_NOT_EMERGENCY__3V3 is on pin 13 as an existing local label).
    Promoted local 'GND' label at (128.27, 78.74) to global to clear the
    last same_local_global_label warning. ERC: 70 → 64.
    [kart-medulla_P1.kicad_sch]
2026-05-04 kart-medulla: add power:PWR_FLAG instances on +3V3, +5V_USB, GND rails
    These nets had only power_in consumers (chip VCC/GND pins + power
    symbols), so ERC fired power_pin_not_driven on every consumer.
    PWR_FLAG (KiCad stdlib) provides a power_out pin to assert "this
    net is supplied from outside". Cached the symbol verbatim from
    KiCad stdlib so lib_symbol_mismatch stays clean. Skipped +5V_REG
    because L7805 OUT (already power_out) drives it. ERC: 64 -> 61.
    3 power errors fixed, 1 remaining (U4 +V on the wrong net).
    [kart-medulla_P1.kicad_sch]
2026-05-04 kart-medulla: add PWR_FLAG on +12V rail (LM358 amp supply)
    Last unflagged power rail. U4 LM358 V+ pin uses +12V for the
    0-5V→0-10V brake-amplifier output, but the +12V net had only
    power_in consumers. PWR_FLAG asserts the rail is driven from
    the main connector. ERC: 61 → 60. All power_pin_not_driven
    errors now cleared.
    [kart-medulla_P1.kicad_sch]
2026-05-04 kart-medulla: split LM358DR into proper multi-unit symbol (op-amp A + B)
    ConvertEDA collapsed both op-amps onto one unit with pins 5/6/7
    geometrically stacked on top of pins 3/2/1, causing pin_to_pin
    errors (OUT1 + OUT2 short). Restructured into KiCad multi-unit
    form: unit 1 keeps pins 1,2,3,4,8 at original lib coords (existing
    U4 wiring preserved untouched); unit 2 contains pins 5,6,7 only.
    Applied to both the project lib and the schematic lib_symbols
    cache. ERC: 60 → 61 (0 errors / 61 warnings). The new
    missing_unit / missing_input_pin warnings are expected — unit B
    is now a separate placeable unit; place it with tie-back wiring
    (IN+ → GND, IN- → OUT) to silence them and document t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
    [kart-medulla_P1.kicad_sch]
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2026-05-04 kart-medulla: NC markers on op-amp B + fix MAX4660 pin 2 etype
    Two cleanups:
    1. Place 3 (no_connect) markers on U1B (LM358 op-amp B) pins 5/6/7
    to silence missing_unit + missing_input_pin warnings.
    2. Fix MAX4660 pin 2 electrical type from no_connect to passive.
    The MAX4660 is a SPDT analog switch with two pins both named
    'NC' in the symbol but with different meanings: pin 2 is the
    *Normally Closed* switch contact (real functional pin, wired
    to PEDAL_ACC__0_5V), pin 5 is genuine *No Connect* (no internal
    silicon). I had set both to no_connect, which fired
    no_connect_connected on pin 2.
    ERC: 61 → 58, 0 errors, 58 warnings (47 wire-endpoint + 11 isolated
    single-pin labe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
    [kart-medulla_P1.kicad_sch]
2026-05-04 kart-medulla: reset PWR_FLAG references to #FLG (let KiCad annotate)
    I had given the PWR_FLAG instances descriptive references like
    #FLG_+3V3, #FLG_+12V etc. KiCad's annotation requires prefix
    letters + number (e.g. #FLG1) and treats anything else as
    unannotated, which makes the GUI fire "Item not annotated"
    errors. Reset all 4 to plain #FLG so the user can annotate via
    Tools → Annotate Schematic.
    [kart-medulla_P1.kicad_sch]
2026-05-04 kart-medulla: demote CMD_ACC__0_5V and CMD_REVERSE to local labels
    These were global_labels left over from the bulk hierarchical→global
    conversion done early in the cleanup. The design is flat single-sheet,
    so global scope is unnecessary and renders inconsistently with the
    rest (boxed hexagon vs. plain text). Demoted both back to (label).
    Also stripped the (property "Intersheetrefs" "${INTERSHEET_REFS}")
    block carried over from the global-label form — local labels don't
    support that template variable, which fired unresolved_variable
    errors after the demotion.
    Includes the user's GUI cleanup of wire endpoints (47 → 26).
    ERC: 0 errors / 38 warnings.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
    [kart-medulla_P1.kicad_sch]
2026-05-04 kart-medulla: fix CN4 I2C labels orphaned by earlier bus rename
    CN4 pins 1 and 2 had labels STEER_SDA__I2C / STEER_SCL__I2C from
    before the I2C bus was renamed to SDA__I2C / SCL__I2C across the
    GPIO expander and ESP32 header. Those two labels never got updated,
    so the steering sensor was electrically NOT connected to the I2C
    bus (would have shown up only at PCB-fab/test stage).
    Renamed CN4 labels to match. ERC: 38 → 36 (2 isolated_pin_label
    clear).
    Also recorded in .agents/error-log.md: I had dismissed all
    isolated_pin_label warnings as "legitimate" without verifying,
    which masked this real bus-rename bug. Lesson: always grep each
    isolated label's name before classifying.
    Co-Authored-By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
    [kart-medulla_P1.kicad_sch]
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2026-05-04 kart-medulla: set new +3V3 power symbol reference to #PWR? for annotation
    The +3V3 symbol I added (replacing the old SPARE__3V3 label) had
    hardcoded Reference "#PWR" which KiCad treats as unannotated → fires
    "Item not annotated" error. Changed to "#PWR?" so Tools → Annotate
    will assign a real number (e.g. #PWR40).
    [kart-medulla_P1.kicad_sch]
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2026-05-07 kart-medulla: integrate SnapEDA MAX4660 footprint+3D, fix hidden wire-disconnect on U14 pin 2
    - Adopt SnapEDA-verified footprint (SOP65P490X110-9N) and .step 3D model for U14 (MAX4660 throttle mux)
    - New 3dmodels/ folder for project-local .step files (referenced via ${KIPRJMOD}/3dmodels/)
    - Add MAX4660 datasheet to datasheets/
    - New parts.md tracking per-part sourcing (manufacturer URLs, SnapEDA download links, replacement notes)
    - Fix cached lib_symbols drift: pin 2 (NC = Normally Closed) was no_connect in the schematic cache but passive in the library; reconciled to passive
    - Fix real wiring bug uncovered by the symbol fix: PEDAL_ACC__0_5V wire ended 8.89mm short of U14 pin 2 — the broke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
    [MAX4660EUA_T.step, kart-medulla_P1.kicad_sch]
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2026-05-07 kart-medulla: NC pins 20/21 (UART0 TX0/RX0)
    GPIO 43/44 are reserved by the dev-board's on-board USB-UART bridge
    (default debug/flash console). They were previously labeled as nets
    "TX0"/"RX0" with one-pin connections, which is misleading and triggers
    ERC. Replaced with no-connect markers + explanatory text on the schematic.
    [kart-medulla_P1.kicad_sch]
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2026-05-07 kart-medulla: NC dead breakout nets (TX1/RX1, LED, USB_D±, SDC_ENABLE)
    Same logic as b07c56f (UART0 NC):
    - TX1/RX1 (U23 pins 19/20, 21/22): UART1 unused — USB-Serial covers
    debug. Frees GPIO38 so the v1.1 onboard RGB LED can be used (close
    the RGB solder bridge on the devkit, no schematic conflict).
    - LED (U24.7): no LED on this board.
    - USB_D+/USB_D- (U24.3/4): no USB connector on this board.
    - SDC_ENABLE (U24.14): orphan single-pin label.
    All six were single-side labels with no internal consumer (only the
    breakout connector). Replaced with no_connect markers + explanatory
    text. Eliminates 4 ERC "Label connected to only one pin" warnings.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
    [kart-medulla_P1.kicad_sch]
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2026-05-07 kart-medulla: clean up MAX4660 GND PWR refs, trace SELECT_THROTTLE, log audit conflation
    - Schematic: rename ugly auto-refs #PWR25ce01 → #PWR042 (pin 7 V−) and
    #PWRdf4d01 → #PWR043 (pin 3 GND) on U14 GND power symbols (manual GUI edit).
    - tasks.md: document SELECT_THROTTLE net membership (U14.6, R32.1, U23.15,
    U23.16) — hardware side complete, firmware GPIO drive is the only open
    item. Also a short explainer task on why power symbols use #PWR refs.
    - .agents/error-log.md: log the conflation error — I treated "firmware
    doesn't reference SELECT_THROTTLE" as evidence the schematic side was
    also unfinished, when the netlist trace was one tool call away.
    - .agents/history.md: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
    [kart-medulla_P1.kicad_sch]
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2026-05-07 kart-medulla: PCB↔schematic resync + agent workflow rules
    PCB sync (the original goal — get ratsnest/Nets count right):
    - Update PCB from Schematic with "Re-link footprints by reference"
    to repair empty symbol associations on every PCB footprint. Brings
    net count from 34 → ~80, ratsnest now populates correctly.
    - Adds CN9, CN10 footprints that existed in schematic but not PCB.
    - Footprint library names normalized to kart-medulla:* prefix.
    - U23/U24 ESP32 header locks preserved (lock warnings benign).
    Schematic cleanup:
    - Delete stray kart-medulla:GND symbol with hidden Reference "U02"
    at (125.73, 311.15) — was buried under a standard power:GND at the
    same junction (redundant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
    [kart-medulla.kicad_pcb, kart-medulla_P1.kicad_sch]
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2026-05-08 kart-medulla: assign CN1–CN10 pins to match ESP32 geometry
    CN1–CN5 (right side, bottom→top) and CN6–CN10 (left side, top→bottom)
    are now wired so each connector pin sits next to the ESP32 pin handling
    its signal — minimizes jumper-wire length when wiring the board.
    30 net assignments (25 label renames + 5 new wire+label pairs) applied
    to kart-medulla_P1.kicad_sch. Verified end-to-end via netlist export:
    all 30 CN pins resolve to the intended global net.
    Rationale and rejected alternatives (notably the MH1↔CMD_STEER_DIR
    swap to cluster halls on one side — rejected because GPIO 0 is a
    strap pin and the SN74LVC3G17 level shifter is push-pull, so a
    pull-up can't override an act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
    [kart-medulla_P1.kicad_sch]
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2026-05-08 kart-medulla: cluster U25 signals on right side (6-label reshuffle)
    U25 (PCF8574 GPIO expander) physically placed near CN3. Re-clustered
    all U25-facing signals on right-side CNs to minimize routing length:
    - CN3 now pure EXP cluster (P1/P2/P3)
    - CN4 carries REVERSE_WIRE + I²C (SDA/SCL) — all U25 control
    - Displaced ESP32 signals (CMD_STEER_DIR/PWM, SDC_IN_LOW_SIDE) moved
    to left CNs (CN8/CN9), where their ESP32 GPIOs cross under the
    module via the bottom layer.
    6 net-label renames on the CN-side; no wire/footprint geometry
    changed. Verified end-to-end via netlist export + ERC clean.
    pinout-cn-connectors.md and history.md updated accordingly.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
    [kart-medulla_P1.kicad_sch]
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2026-05-08 kart-medulla: swap CN5.3 GND ↔ CN9.3 EXP_P4
    EXP_P4 was the last U25-related signal still on a left-side CN after
    yesterday's cluster reshuffle. Moved to CN5.3 (right) so all four
    PCF8574 expander outputs (P1–P4) sit on right-side CNs near U25.
    GND moves to CN9.3 in its place.
    [kart-medulla_P1.kicad_sch]
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2026-05-09 medulla: restore 3D model bindings on 54 footprints
    Footprint instance-level (model ...) blocks had been stripped from
    the .kicad_pcb in an earlier round of layout work, leaving the 3D
    viewer almost empty. Recovered them by walking a local KiCad
    auto-backup (kart-medulla.kicad_pcb.bak.20260509f, 55 refs) and
    copying each footprint's 3D model block (path + offset + scale +
    rotate) into the matching refdes on the current PCB. Layout,
    routing, and silk untouched.
    PAD1-PAD4 (corner mounting holes) intentionally left without 3D
    models.
    Long-term fix is to bind 3D models at the kart-medulla.pretty
    library level instead of instance-level so the bindings survive
    future re-imports. Tracked separate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
    [kart-medulla.kicad_pcb]
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2026-05-09 medulla: auto-place silkscreen reference designators
    Used CGrassin/kicad-auto-silkscreen plugin to optimize refdes
    positions, avoiding overlap with pads, vias, and other footprints.
    [kart-medulla.kicad_pcb]
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2026-05-09 medulla: drop Power class min track 0.5 → 0.3 mm, widen power tracks
    The medulla Power class only carries logic-level rails (+12V, +5V_USB,
    +5V_REG, +3V3) feeding ICs/op-amps/sensors — sub-1 A loads. IPC-2221
    gives 0.30 mm at 1 oz copper ~0.7 A continuous, plenty of margin.
    - kicad_dru: power-track-width rule 0.5mm → 0.3mm with updated rationale
    - kicad_pro: Power netclass default track 0.5 → 0.3 mm
    - docs/drc-aisler.md: rewrote "Why 0.5 mm for Power" → 0.3 mm
    - kicad_pcb: applied netclass width via Edit Track & Via Properties
    DRC: track-width errors gone (~80 → 0), but unconnected items jumped
    3 → 39 from endpoint shifts during widening — to fix next.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
    [kart-medulla.kicad_pcb]
2026-05-09 medulla: DRC cleanup — 0 errors after rule + footprint + zone fixes
    Power-class track-width minimum fully removed (was 0.5 → 0.3 → none).
    The medulla Power-class rails (+12V/+5V_USB/+5V_REG/+3V3) feed only
    sub-100mA logic IC / op-amp / sensor loads; small QFN/SOT-23 fanout
    needs 0.2 mm pitch routing on those rails. Power class still applies
    clearance (0.25 mm) and via size (0.8/0.4 mm). Updated kicad_dru,
    kicad_pro Power netclass track_width, and docs/drc-aisler.md.
    Added rule area polygon ("fine-pitch-smd") around U14 with custom DRC
    rule exempting intra-area pad-pad / track-pad clearance — handles
    SOIC-8 0.65mm pitch's intrinsic 0.18mm pad-pad clearance.
    Fixed 6 rear solder mask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
    [kart-medulla.kicad_pcb]
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2026-07-30 medulla: route the valve command out at 0-10V; restore the DAC->amp copper
    Schematic: one label, at (218.44, 48.26) on CN10 pin 2's stub, renamed
    CMD_BRAKE__0_5V -> CMD_BRAKE__0_10V. Every connection in this chain is a label on
    a stub, so nothing else moved. Netlist now splits correctly: CMD_BRAKE__0_5V =
    U13.10 + U1.3, CMD_BRAKE__0_10V = CN10.2 + R19.2 + U1.1. ERC 0 violations.
    PCB: CN10 pad 2's net updated, then routed to the 0-10V net on F.Cu - 45 deg from
    (74.5, 90.9999) to (81.0727, 97.5726), east to (87.0, 97.5726), 0.6/0.3 via down
    onto the existing B.Cu stub between U1.1 and R19.2. F.Cu because that corridor is
    empty on the front layer while B.Cu is not. Clears CN10.1's through-hole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
    [kart-medulla.kicad_pcb, kart-medulla_P1.kicad_sch]
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2026-07-31 rename CMD_BRAKE -> CMD_PRES; file the MCP4922 datasheet and close two open numbers
    Net rename (task item 3): CMD_BRAKE__0_5V -> CMD_PRES_DAC__0_5V and CMD_BRAKE__0_10V ->
    CMD_PRES__0_10V, following the throttle channel's internal-vs-exported pattern. CMD_PRES
    because it is a pressure setpoint for a proportional regulator, not a brake-force command.
    Applied to schematic (4), PCB (15) and both pinout docs so the two stay in parity. ERC 0
    violations, DRC 0 violations, 0 unconnected. The one remaining CMD_BRAKE is under the
    'Legacy: classic ESP32' heading and correct there.
    MCP4922 datasheet filed (item 4). Output swing is 0.01 V to VDD-0.04 V typical, so full
    scale on the 5 V rail is ~4.96 V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
    [kart-medulla.kicad_pcb, kart-medulla_P1.kicad_sch]
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
